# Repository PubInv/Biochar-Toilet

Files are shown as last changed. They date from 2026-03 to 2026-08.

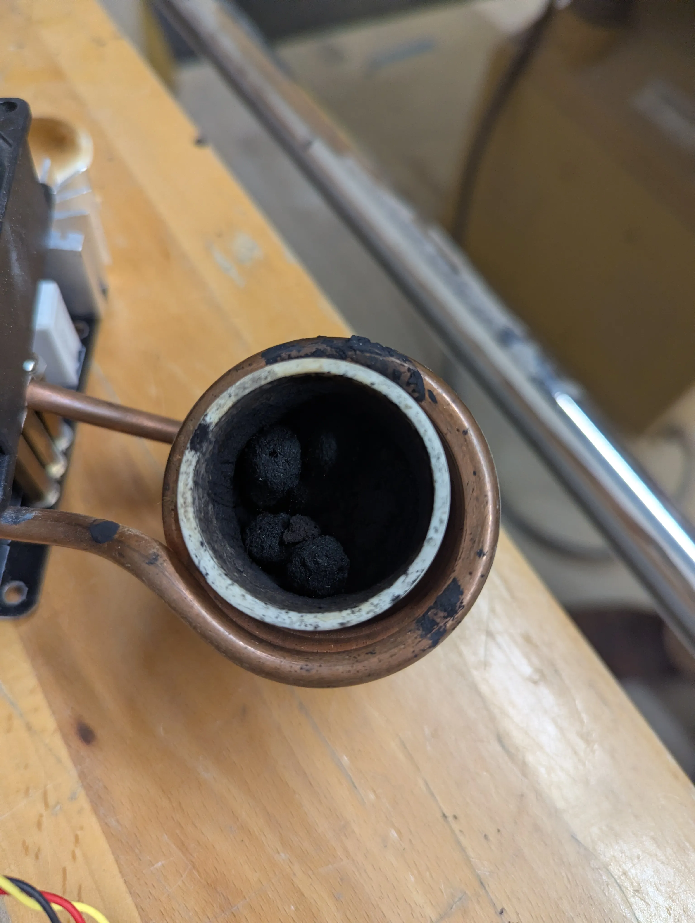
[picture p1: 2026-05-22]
images/PXL_20260327_165919695.webp

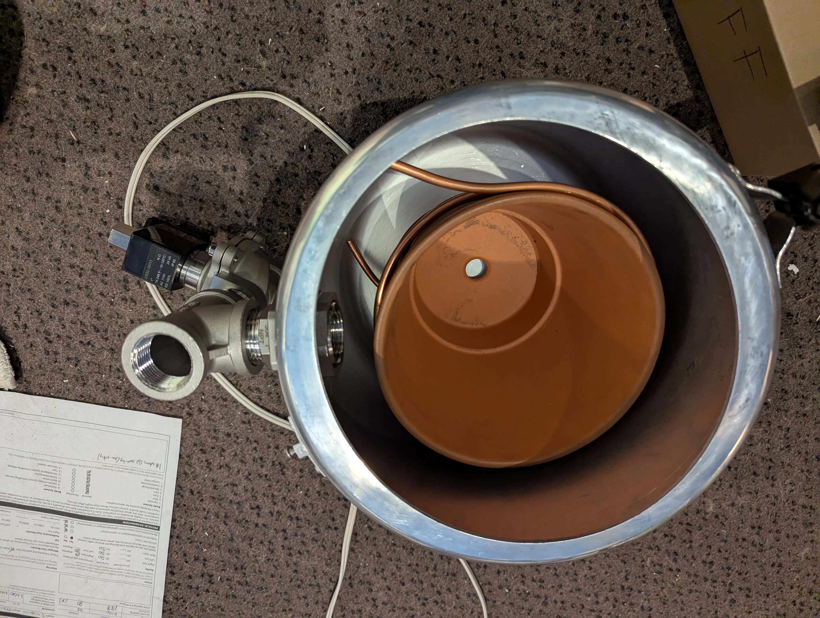
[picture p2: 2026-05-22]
images/PXL_20260417_191130522.webp

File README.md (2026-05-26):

# Current Status

Phase 1 (conductive heating prototype) is complete. All experiment data, firmware, schematics, PCB design files, and progress reports are in the [`Conductive Heating Prototype/`](https://github.com/PubInv/Biochar-Toilet/tree/main/Project%20Files/Conductive%20Heating%20Prototype) folder.

We're now in Phase 2: induction heating using a magnetite matrix. The shift from resistive heating matters because induction generates heat directly inside the charring cup — no exposed coils corroding in the process environment, and faster energy delivery to the material itself.

Ongoing experiment logs are in the [Progress Reports](https://github.com/PubInv/Biochar-Toilet/blob/main/Project%20Files/Progress%20Reports.md).

Screenshot 2025-11-21 at 6 10 39 PM

---

# Biochar Toilet

A reliable toilet that could quickly reduce human fecal matter to completely sanitary biochar would make the poorest people of the
Earth healthier. In many communities, Western-style sewage systems would be very expensive and impractical due to
geology, the lack of density in farming communities made of small land holdings, a lack of capital, and a lack of
social and political organization to dig trenches and lay pipes efficiently.

Reducing a typical human stool to biochar requires an energy input of about 600 kilojoules (see detailed analysis in referenced spreadsheet).
Even for the poorest people, the cost of this electricity is quite low---less than one US cent $0.01USD. One kilowatt hour is 3.6 MJ (megajoules).
Expensive electrical power around the world is $0.45/kWh is $0.075 USD--or less than eight cents. Even if our toilet is inefficient, it
seems possible to make a toilet whose operating cost is affordable for the poorest people, at $27.375 per year (this cost does not include
the capital costs of the toilet).

Biochar can be used as a fuel or a garden amendment. Note, however, that human stools are so small (128 grams nominally) that this is not a meaningful approach for carbon sequestration.

# Initial Design Idea

The problem of toilets is a widely researched area. Our approach may be slightly novel. We start from some assumptions:

1. Electricity is an input.
2. Complete biological safety of the end product is required.
3. We choose to temporarily ignore the capital costs of the toilet in our research.
4. Because we have to char in the absence of oxygen to prevent combustion, we can assume that we need an air-tight or pressure controlled reaction vessel.
5. A major problem in charring is to first dry the sample, and drying is primarily a problem of water transport.

We therefore conclude that our basic design will be a sealed reaction vessel with a valve that allows steam to be transported out
of the reaction chamber. We will heat the chamber contents until a desired pressure is created and then transport the water
vapor away by opening the valve. The valve will be controlled so as to avoid most gases (air) from entering the chamber.
Opening the valve will "flash" the water in the sample into steam, which will have the desirable properties of being
extremely murderous to any organisms present in the sample, and physically destructive to both plant and animal cells.
It may even physically disrupt the sample, which could be advantageous.

When the sample is sufficiently dry, we will heat it to charring temperature. When the sample is fully charred, and then cooled
and possibly wetted to avoid spontaneous combustion, the operator will be alerted that the sample is safe to remove and either combust or use as a garden amendment.

# Energy Analysis

Volunteer Nupur Bhalla working with Invention Coach Robert L. Read has produced a [Google Sheet](https://docs.google.com/spreadsheets/d/1ZwIqP0B2wM6QrpZTNiK1hNnNmIEIal7qxYdgEJz8Iog/edit?usp=sharing) representing an energy analysis of the drying and heating process.

# Heating Mechanisms

Since we will have a sealed metal reaction vessel, radio frequency (RF) heating is a possibility.
However, it is expected to become less effective as the sample dries.
We therefore intend to explore the possibility of using simple Joule resistive heating of a stainless steel vessel directly.
RF heating, however, has the advantage of heating the sample volumetrically (not requiring conduction), which may be a tremendous advantage.

# Phase 1: Conductive Heating Prototype (Complete)

Phase 1 used a pressure cooker as the reaction vessel, a hot plate controlled by an SSR, and an ESP32-based sensing system. The goal was to confirm the core architecture before committing to higher-temperature methods.

It worked. When pressure drops below ~1 PSI while temperature keeps climbing, the system correctly identifies the dry state and cuts heater power automatically. Flash decompression also checked out — opening the solenoid under pressure causes trapped water to flash to steam. A bread charring test (~110°C, 2h40m) produced a visibly charred loaf, though the dryness algorithm didn't trigger since the bread's low moisture content didn't produce a distinct enough pressure signature during drying. Soot accumulation on the lid also flagged particulate management as something to design for in future iterations.

The hard limit we hit: full charring temperatures aren't safe inside a standard pressure cooker. Lawrence Kincheloe suggested placing an inner cup (heated by a silicon nitride igniter) inside the vessel so the outer shell stays cool — that idea feeds directly into Phase 2.

We also designed a custom control PCB for this phase (ESP32-H2, v0.3.0) with dual MOSFET valve drivers, dual SSR outputs, a pressure ADC, and a MAX31855 thermocouple interface. Everything is in the [`Conductive Heating Prototype/`](https://github.com/PubInv/Biochar-Toilet/tree/main/Project%20Files/Conductive%20Heating%20Prototype) folder.

# Phase 2: Induction System Development (In Progress)

We've switched from resistive heating to pulsed induction using a magnetite matrix. The magnetite sits inside the charring cup and converts the induction field directly into heat — no exposed coils, no conduction losses through the vessel wall.

Early results from Lawrence Kincheloe and Peter are encouraging. Five grams of magnetite reached 740°F in 60 seconds; the same mass of carbon steel bearings only hit 130°F. Volume-matching the steel to the magnetite closes the gap considerably (~940°F peak), which suggests surface area and density matter more than material choice at this scale. They also charred cheese puffs at 833°F over 16 minutes in open air, with residue on the crucible cap showing evidence of partial pyrolysis.

Full experiment logs are in the [Progress Reports](https://github.com/PubInv/Biochar-Toilet/blob/main/Project%20Files/Progress%20Reports.md).

# Research Plans

The next step is pushing the induction system to actual charring temperatures — hot enough to produce biochar from organic material comparable to human stool. Work on coil geometry and magnetic field focusing is ongoing in parallel with fabrication.

Basic Biochar Toilet Design (https://github.com/user-attachments/assets/ea41856b-7663-43a1-bf12-8a3a2311aef8) 

# References

"An Experimental 13.56 MHz Radio Frequency Heating System
for Efficient Thermal Pretreatment of Wastewater Sludge",
Md. S. Ferdous, Ehssan H. Koupaie, Cigdem Eskicioglu, and Thomas Johnson*

# Volunteer Opportunities

This project is still active. If you have a background in mechanical engineering, heat engineering, or chemistry, we'd be glad to hear from you.

Reach out to Inventor Coach [Robert L. Read](https://github.com/PubInv/Biochar-Toilet/blob/main/read.robert@gmail.com) or Volunteer Coordinator [Miriam Castillo](https://www.linkedin.com/in/cstllgtrrz/). More at the [Volunteer Page](https://www.pubinv.org/volunteer/).

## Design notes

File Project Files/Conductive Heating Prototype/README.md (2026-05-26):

# Conductive Heating Prototype — Phase 1

**Biochar Toilet Project | Phase 1 Documentation** |
**Contributor:** Hardhik Pyla ([@hardhik03](https://github.com/hardhik03)) |
**Period:** November 2025 – May 2026 |
**Status:** Complete

---

## Overview

Phase 1 of the Biochar Toilet project was a proof-of-concept prototype to validate the core system architecture before advancing to higher-temperature charring methods. The goal was to build the smallest, safest system possible — one that could demonstrate:

1. Reliable pressure and temperature sensing inside a sealed reaction vessel
2. Automatic dryness detection using temperature–pressure divergence logic
3. Autonomous heater shutoff via SSR when the dry state is detected
4. Flash decompression: opening a solenoid valve under pressure to flash-boil trapped water into steam (providing mechanical sterility)

The reaction vessel was a standard pressure cooker. The heating source was a hot plate controlled by a solid-state relay (SSR). Sensing and control were handled by an ESP32-based embedded system, later migrated to a custom-designed control PCB.

---

## System Architecture

```
[Pressure Cooker] ──── [K-type Thermocouple] ───► [ESP32-H2 Control Board]
      │                                                      │
      ├──── [Analog Pressure Sensor] ───────────────────────►│
      │                                                      │
      └──── [Solenoid Valve 1] ◄──── [MOSFET Driver] ◄──────┤
                                                             │
[Hot Plate] ◄──── [SSR 1] ◄──── [NPN BJT Driver] ◄──────────┘
```

**Dryness Detection Logic:**
When pressure drops below ~1 PSI and stays there for 15 seconds (after an initial active cycle above 2 PSI), the system latches the "dry" flag and disables the heater SSR. This is based on the observed behavior that temperature rises sharply while pressure stays low once all moisture has been driven off.

**Valve Control Logic:**
The solenoid valve opens when pressure reaches 8 PSI and closes at 7 PSI (hysteresis band), releasing steam to the condenser/containment vessel.

**Temperature Control:**
A proportional controller (Kp = 0.03) targets 200°C with a 2-second PWM window. An exponential moving average (α = 0.10) smooths thermocouple readings.

---

## Hardware

| Component | Description |
|---|---|
| Reaction vessel | Standard pressure cooker |
| Microcontroller | ESP32 (breadboard) → ESP32-H2 DEVKITM-1-N4 (custom PCB) |
| Temperature sensor | K-type thermocouple + MAX31855 breakout (SPI) |
| Pressure sensor | Analog 0–100 PSI, read via ADC with voltage divider (0–5V → 0–3.3V) |
| Solenoid valve | 12V solenoid, driven by IRLB3813PBF N-channel MOSFET |
| Heater control | Solid-state relay (SSR 1), NPN BJT driver — active HIGH |
| Hot plate | External AC hot plate, switched via SSR |
| Custom PCB | Bio-Char Control Board v0.1.0 (KiCad 9, 2-layer FR4, ~$48 BOM) |

---

## Pin Configuration

The table below reflects the **working firmware pin assignments** as validated during PCB bring-up. These differ from the original KiCad schematic assignments — see the [Pin Change Notes](#pin-change-notes) section below.

| GPIO | Function | Direction | Notes |
|---|---|---|---|
| GPIO0 | MAX31855 CLK | Output | SPI clock |
| GPIO1 | MAX31855 CS | Output | SPI chip select |
| GPIO2 | MAX31855 DO | Input | SPI MISO — read-only, no MOSI needed |
| GPIO3 | Pressure Sensor ADC | Input | ADC1_CH3, 0–100 PSI via voltage divider |
| GPIO4 | SSR 1 / Heater | Output | **Active HIGH** — drives NPN BJT base to complete SSR circuit |
| GPIO5 | SSR 2 | Output | Reserved — not currently active (see firmware comments) |
| GPIO10 | Solenoid Valve 1 | Output | MOSFET (IRLB3813PBF) driven |
| GPIO11 | Solenoid Valve 2 | Output | Reserved — not currently active (see firmware comments) |

### Pin Change Notes

During PCB bring-up, the SSR control pins had to be remapped due to a conflict with the ESP32-H2's internal crystal peripheral:

- **GPIO13 and GPIO14** are internally tied to the ESP32-H2's 32 kHz RTC crystal oscillator. The original schematic routed SSR1 and SSR2 control lines to these pins. On Test 1 (05/06/2026), both SSR outputs were unresponsive — the GPIOs could not be driven as outputs while the crystal is active.
- As a Test 1 workaround, SSR1 and SSR2 were manually driven from **GPIO4 and GPIO5** (open pins on the board), confirming the BJT and SSR circuitry was otherwise functional.
- On 05/14/2026, the GPIO13 and GPIO14 traces were physically cut and jumper wires were soldered from GPIO4 → SSR1 and GPIO5 → SSR2 pads. This hardware rework makes the board match the firmware pin assignments permanently.
- The corrected routing will be incorporated into the next PCB design revision.

### Heater/SSR Logic Change

The original Arduino firmware used **active LOW** logic for the heater (GPIO4 LOW = SSR ON, sinking to GND via the SSR's internal optocoupler). The PCB design introduced an NPN BJT between the ESP32 GPIO and the SSR input, which inverts the signal:

```
GPIO4 HIGH → BJT base HIGH → collector pulls SSR input → SSR ON
GPIO4 LOW  → BJT OFF       → SSR input floating        → SSR OFF
```

The ESP-IDF firmware (`Firmware/main/main.c`) uses **active HIGH** accordingly. The `set_heater()` function drives GPIO4 HIGH to turn the heater on and LOW to turn it off.

---

## Known Errors and Issues

| # | Issue | Status | Notes |
|---|---|---|---|
| 1 | ADC non-linearity at low raw values (<350) | Mitigated | Readings below ~0.5 PSI fluctuate. DRY_PRESSURE_MAX threshold (1.0 PSI) provides sufficient headroom for reliable detection. |
| 2 | MAX31855 returns NaN on first read after power-on | Handled | ~100ms settling time required. EMA initialisation stays NaN until a valid reading arrives — no false triggers. |
| 3 | GPIO3 shared with JTAG MTDI | Known | Disconnect JTAG debugger before running in production, or remap ADC to GPIO4/5 if debugging under sustained load. |
| 4 | GPIO13/GPIO14 RTC crystal conflict — SSR pins non-functional | Resolved (05/14/2026) | Original schematic routed SSR1/SSR2 to GPIO13/GPIO14, which are internally tied to the 32 kHz RTC crystal on the ESP32-H2. Confirmed on Test 1 (05/06): both SSR outputs were unresponsive. Test 1 workaround: SSR driven manually from GPIO4/GPIO5. Permanent fix: traces to GPIO13/GPIO14 cut and jumper wires soldered to GPIO4/GPIO5 pads. Next PCB revision will correct the routing. |
| 5 | D2/D5 diode voltage drop — solenoid safety switches not opening | Resolved (05/14/2026) | 1N4148 diodes on the solenoid valve safety switch circuits had a forward voltage drop high enough to prevent the gate logic from pulling low cleanly, blocking valve operation. Bypassing the diodes confirmed the MOSFET/solenoid path was functional. D2 and D5 replaced with 1N4001 diodes; valve operation re-verified successfully. |
| 6 | Bread charring — dryness detection did not trigger | Investigated | Bread had insufficient initial moisture to produce a distinct pressure signature during drying. Detection heuristic works correctly for water-heavy samples. |

---

## Experiment Timeline

See [`Progress Reports.md`](https://github.com/PubInv/Biochar-Toilet/blob/main/Project%20Files/Progress%20Reports.md) for full dated entries. Summary:

| Date | Milestone |
|---|---|
| Nov 21, 2025 | Pressure sensor schematic designed |
| Dec 5, 2025 | Initial pressure sensor physical calibration and error testing |
| Dec 11, 2025 | Dryness detection breadboard prototype — valve, pressure, dryness logic validated |
| Jan 16, 2026 | Microcontroller + solenoid valve + SSR hardware integration |
| Feb 13, 2026 | Bread charring test with auto-shutoff — end-to-end system validated |
| Mar 5–18, 2026 | Custom Control Board PCB design (v0.1.0) — Gerbers generated |
| May 6, 2026 | PCB Board Test 1 — PSI and dry detection verified; GPIO13/14 crystal conflict and D2/D5 diode drop identified |
| May 14, 2026 | Hardware rework — GPIO13/14 traces cut, SSR lines jumpered to GPIO4/5; D2/D5 replaced with 1N4001; valve operation re-verified |

---

## Key Results

**Dryness Detection:** Successfully confirmed. When pressure falls below 1 PSI for 15 sustained seconds following an active cycle, the system correctly identifies the dry state and disables the heater.

**Flash Decompression:** Validated. Opening the solenoid valve under pressure causes water to flash to steam. However, at ~15 PSI, the valve restriction prevented instantaneous pressure drop — steam flowed continuously rather than flashing off in a single burst.

**Bread Charring Test (Feb 13, 2026):** A loaf of bread was heated inside the sealed pressure cooker at ~110°C for approximately 2 hours and 40 minutes. The loaf was visibly charred. The dryness detection algorithm did not trigger in this run (see Known Errors #5). Soot accumulation on the chamber lid was observed, raising particulate management as a future design concern.

**Key Finding — Safety Limit:** Full charring temperatures cannot be safely reached inside the pressure cooker vessel. Lawrence Kincheloe proposed an inner charring cup (heated by a silicon nitride igniter) inside the pressure cooker, keeping the outer vessel cool. This informed the transition to Phase 2 (induction heating).

---

## Firmware

Two firmware versions exist for this prototype:

| File | Platform | Notes |
|---|---|---|
| `Firmware/main/main.c` | ESP-IDF v5.x | Current — active HIGH heater logic, reserved pins commented |
| *(Arduino reference)* | Arduino IDE | Original breadboard firmware; superseded by ESP-IDF version |

The ESP-IDF firmware (`Firmware/main/main.c`) implements all three control loops simultaneously:
- Pressure-based valve hysteresis (8 PSI on, 7 PSI off)
- Dry boiler detection (sustained low-pressure latch after active cycle)
- Proportional temperature control with EMA smoothing and 2-second PWM window

To build and flash:
```bash
idf.py set-target esp32h2
idf.py build
idf.py -p PORT flash monitor
```

Root-level Python scripts (`dryness_monitor.py`, `valve_controller.py`, and their tests) were earlier-stage software prototypes for the same logic.

---

## PCB Design

The Bio-Char Control Board v0.1.0 is documented in detail in the main project PCB Design folder. Key specs:

- **MCU:** ESP32-H2-DEVKITM-1-N4 (RISC-V 96MHz, WiFi 802.11n, BLE 5.2)
- **Power:** 12V input → R-78E5.0-1.0 switching regulator (5V) + 2A PTC fuse + reverse-polarity protection
- **Outputs:** 2× IRLB3813PBF MOSFET solenoid drivers, 2× NPN BJT-driven SSR outputs (active HIGH)
- **Sensors:** MAX31855 SPI thermocouple, analog pressure ADC with voltage divider
- **BOM cost:** ~$48 (Mouser, March 2026)
- **Manufacturing files:** Gerbers and drill files included

---

## Conclusions and Lessons Learned

1. Temperature–pressure divergence is a reliable proxy for sample dryness and works well as an autonomous shutoff trigger.
2. Valve restriction geometry matters significantly for flash decompression — a lower-restriction valve is needed for true instantaneous pressure drop.
3. Low-moisture samples (like dry bread) do not produce a clear pressure signature during drying, requiring either a different detection heuristic or moisture pre-conditioning.
4. Soot and particulate management inside the reaction vessel needs to be designed for from the start in future iterations.
5. Charring temperatures (>400°C) cannot be safely achieved in the pressure cooker configuration — an inner heated vessel is necessary.
6. The custom PCB successfully consolidates all sensing and control onto a single board, validating the embedded architecture for future phases.
7. Crystal-reserved GPIOs on the ESP32-H2 (GPIO13, GPIO14 for the 32 kHz RTC crystal) must be identified and avoided during schematic design — they appear usable in simulation but are unresponsive as outputs on hardware while the crystal is active.
8. 1N4148 diodes are inadequate for solenoid valve safety switch circuits at the currents involved — the forward voltage drop prevents clean gate logic switching. 1N4001 is the correct replacement.

---

## Files in This Folder

```
Conductive Heating Prototype/
├── README.md                        ← This file
└── Firmware/
    ├── CMakeLists.txt               ← ESP-IDF top-level build file
    └── main/
        ├── CMakeLists.txt           ← Component registration
        └── main.c                   ← ESP-IDF integrated control firmware
```

Hardware files (schematics, PCB design, test videos) are in the corresponding subfolders of the main project directory and cross-referenced above.

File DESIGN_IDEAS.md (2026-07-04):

This design solves two big problems: **thread fouling** (bentonite dust destroys threads) and **mechanical complexity** (clamps/bolts require extra parts).

Here is how to adapt this cookware concept into a rugged industrial sanitation device.

### 1. Why this works for "Severe Service" (Dust + Pressure)

The oval lid is that the **lid itself is physically larger than the hole** along one axis.

* **Blowout Proof:** In a standard "outside" lid, if the bolts fail, the lid becomes a projectile. In this "inside" design, the pressure pushes the lid *against* the metal rim of the chamber. It is mechanically impossible for the lid to blow off while pressurized.
* **Foul-Resistant:** Because there are no threads, there are no small crevices for your bentonite/magnetite dust to pack into. If dust gets on the rim, the massive force of the internal pressure (the "self-energizing" effect) will simply crush the gasket over the dust, maintaining the seal.

### 2. The Geometry: How to Manufacture It

You do not need complex castings. You can manufacture this using standard stainless steel plate.

* **The Shape:** Both the chamber opening and the lid are **Ellipses** (ovals).
* *Example:* If your opening is 6 inches wide (minor axis) and 7 inches long (major axis), your lid would be 6.5 inches wide and 7.5 inches long.

* **The Insertion Motion:** To insert the lid, you turn it 90 degrees so the lid's *short* side fits through the hole's *long* side. Once inside, you rotate it back 90 degrees and pull it up.
* **Material:** 316 Stainless Steel is ideal for urine/corrosion resistance.

### 3. Adapting for Automation (The "Internal Hinge")

The only downside of the Indian cooker design is that it requires a complex human hand motion (insert, twist, rotate, pull). To make this "mechanically simple" for a device that might be automated or operated easily by a user:

**Add a Single Internal Hinge.**
Instead of a loose lid, attach the oval lid to a hinge *inside* the vessel.

* **Operation:** When the user (or actuator) pushes a lever, the lid swings down and "collapses" slightly into the chamber.
* **Closing:** A spring pulls the lid back up against the hole.
* **Benefit:** This keeps the lid aligned perfectly every time. The user doesn't have to fiddle with the geometric puzzle of fitting the oval through the hole; the hinge guides it.

### 4. The Seal Interface (Combining your ideas)

To make this work with the "high compliance" idea:

1. **The Gasket:** Place a thick, soft **Silicone or EPDM gasket** around the *top rim* of the oval lid.
2. **The Seat:** The rim of the chamber opening should be smooth.
3. **The "Pre-Tension":** You mentioned a "partial seal." In the Indian cooker, a handle clips onto a bar to pull the lid up gently. For your device, use a **Simple Cam Lever**.
* *Step 1:* User drops lid in.
* *Step 2:* User pulls a small lever that pulls the lid up with ~5 lbs of force. This squishes the soft gasket just enough to make it airtight.
* *Step 3:* Induction starts -> Pressure builds -> Lid seals with 1000+ lbs of force.

### 5. Specific Caution: Induction Heating

* **Risk:** If your induction coils are wrapped around the *outside* of the stainless steel chamber near the lid, the **lid itself might heat up** via induction, potentially melting your gasket.
* **Solution:** Ensure your induction coils are focused lower down on the magnetite payload, or use a non-conductive ceramic/composite spacer ring between the heated zone and the steel sealing rim.

### Summary

It is the most robust, fail-safe, and foul-resistant pressure vessel design available.

* **Action:** Design an elliptical opening.
* **Seal:** Top-mounted gasket on the lid.
* **Mechanism:** "Drop, Twist, Pull" (manual) or "Internal Hinge" (semi-auto).

---

## Update: Critical Design Decision - The "Potted" Internal Coil

This is a critical design decision.

For your specific goal—heating the **Magnetite** directly (to use its high surface area for rapid evaporation)—the answer is **INSIDE**.

### The Physics: Why "Outside" Fails

If you wrap induction coils around the *outside* of a stainless steel or aluminum pressure vessel:

1. **Faraday Cage Effect:** The metal wall will intercept the magnetic field.
2. **Wall Heating:** The induction energy will heat the **chamber wall**, not the magnetite. The wall will get extremely hot, and the magnetite will only heat up slowly via conduction from the wall. This defeats the purpose of using magnetite as a volumetric heating element.
3. **Aluminum Efficiency:** If you use Aluminum, it is so conductive that it will reflect/absorb almost 100% of the field instantly.

### The Solution: The "Potted" Internal Coil

You must place the coils **inside** the pressure boundary, but you cannot expose bare copper coils to urine and abrasive clay.

* **Design:** Cast the copper induction coil inside a cylinder of **high-temperature refractory cement** or **castable silicone**.
* **Function:** This creates a "removable liner" (like a bucket). The waste goes inside this liner.
* **Safety:** The Stainless Steel pot handles the **pressure**. The Ceramic Liner handles the **electricity and heat**.

### 2. The Magnetite Catalyst (CO & NOx Killer)

Magnetite acts as a dual-function catalyst here:

1. **Oxidation:** Converts Carbon Monoxide () to Carbon Dioxide ().
2. **De-NOx (SCR):** Your waste contains **Urine** (Ammonia/Urea). In the presence of Magnetite and heat, the Ammonia reacts with Nitrogen Oxides () to form harmless Nitrogen () and Water. This is the exact principle used in diesel trucks (SCR), but you are generating your own "Diesel Exhaust Fluid" (ammonia) from the urine!

**Heating Method:**

* **Do not use a second induction coil.** It adds massive complexity (interference between coils, dual power supplies).
* **Use a Cartridge Heater.** A simple, robust stainless steel heating rod inserted down the center of your catalyst tube. It is cheap, easy to control (PID), and robust.

### 3. Updated Design: The "All-in-One" Lid Assembly

* **The Pot:** Remains a simple Oval shell.
* **The Liner:** Remains the Ceramic/Induction bucket.
* **The Lid:** Now features a **"Reaction Tower"**.
* **Bottom:** Steam Valve.
* **Middle:** Magnetite Catalyst Chamber (heated).
* **Top:** Clean Exhaust Outlet.

### 4. Technical Explanation of the "Tower"

#### A. The Steam Cleaning Valve (Blue Block)

* **Placement:** Directly above the lid center hole.
* **Logic:** The valve is the "Gatekeeper."
* **Phase 1 (Cooking):** Valve Closed. Pressure builds to 15 PSI. Temperature hits 121°C. Sterilization occurs.
* **Phase 2 (Venting):** Valve Opens. The 15 PSI pressure blasts steam through the valve. This high velocity prevents "gunk" from settling on the seat.
* **Component:** Use a **PTFE-seated Stainless Steel Solenoid Valve** (rated for >180°C steam).

#### B. The Magnetite Catalyst (Dark Grey Cylinder)

* **Placement:** Immediately *after* the valve.
* **Why here?** The gas leaving the valve is hot, but maybe not hot enough for catalysis (needs ~300°C+).
* **The Heater (Gold Rod):** A **Cartridge Heater** runs down the center of the pipe.
* It heats the Magnetite pellets surrounding it to ~350°C.
* As the VOCs, CO, and Steam pass through the hot pellets, they are "cracked" and oxidized.
* **Efficiency:** Because the gas is forced through the hot pellet bed, contact time is high. The "Cartridge Heater in the Center" is the most energy-efficient way to heat a gas stream (heating from the inside out).

#### C. Electrical Feedthrough (Goldenrod)

* Since the coil is inside the pot, we need to get power to it.
* The Lid has a **High-Amperage Ceramic Feedthrough**.
* **Connection:** When you lower the lid into the pot, you plug the coil into the bottom of the lid (using a high-temp connector like a ceramic terminal block), then twist and lock the lid.

### 5. High-Temperature Bottom Cartridge (H2S Scrubbing)

To prevent downstream corrosion of the steam valve and heat exchanger, a high-temperature scrubbing cartridge is integrated at the bottom of the vessel.

* **Placement:** Located at the base of the reaction vessel, serving as the exit "choke point" for the downdraft gas flow.
* **Composition:** A modular Silicon Carbide (SiC) and Magnetite matrix.
* **Function:** Operates at peak induction temperatures (800°C+) to chemically strip Hydrogen Sulfide (H₂S) from the syngas stream before it exits the vessel. This protects the stainless steel solenoid valve and thermal recovery hardware from sulfuric acid corrosion.
* **Maintenance:** Designed as a drop-in replaceable cartridge.

---

## Future Phases: Syngas Processing and Advanced Catalysis

For detailed engineering considerations on managing exhaust gases, practical lean combustion syngas conversion, and sulfur mitigation strategies within the biochar mix, please refer to the advanced Phase 3 memo: [Syngas Processing Memo](Project Files/Memos/Syngas_Processing_Memo.md).

---

## System Monitoring & Valorization

The project utilizes a pressure cooker, modified with a 1" solenoid and an integrated induction heating loop. The induction loop itself is quite large, needing to encompass human fecal matter. The system uses a pressure sensor to monitor the state of the system; because we use pressure, we can monitor the state of valorization.

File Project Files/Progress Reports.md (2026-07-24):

## **[07/24/2026]**

**Phase 3 Ideation – Physical System Frame Design**

Worked in FreeCAD 1.1 to pull together Hawkins 12L Pressure Pot assembly components and to start initial system frame rigging design using 20mm x 40mm extruded aluminum and compatible hardware. Uploaded current FCStd file status into the Public Invention/Biochar-Toilet/Project Files/CAD Files folder as "Frame for Assembly_v2.FCStd". Once all essential components are uploaded, and component assembly layout has been established, specific joint bracket hardware will be added to a parts list to create a Frame BOM, and custom brackets will be designed and sent to fabrication as-needed, with details uploaded to Frame BOM. 

## **[07/03/2026]**

**Phase 3 Ideation – High-Temperature H2S Scrubbing Refinement**

Refined the Phase 3 sulfur mitigation strategy by proposing a high-temperature Silicon Carbide (SiC) and Magnetite cartridge at the bottom of the reaction vessel. This cartridge serves as the final high-temperature "choke point" (800°C+) for downdraft syngas, maximizing H2S removal efficiency before the gas reaches the solenoid valve and external heat recovery hardware. This addition completes the three-tier sulfur defense architecture: in-situ fixation (biochar), peak-temp scrubbing (bottom cartridge), and low-temp polishing (iron sponge). Updates were applied to the [Syngas Processing Memo](Memos/Syngas_Processing_Memo.md) and `DESIGN_IDEAS.md`.

## **[07/01/2026]**

**Phase 3 Ideation – Syngas Processing and Ceramic Liners**

Documented advanced Phase 3 concepts regarding the management of syngas exhaust and modular ceramic liner assemblies. A new engineering memo was created detailing the highly practical lean combustion pathway for oxidizing Syngas into CO₂, and exploring sulfur mitigation strategies directly within the biochar mixture using in-situ fixation and Iron Sponge dry scrubbers. Furthermore, design guidelines for "leaky" modular ceramic assemblies with slip-fit baffles were established to prevent thermal shear failure in the heat exchanger. The complete analysis is recorded in the [Syngas Processing Memo](Memos/Syngas_Processing_Memo.md) and linked in `DESIGN_IDEAS.md`.

## **[06/17/2026]**

**Post presentation notes on live demo**

Firmware needed a slight update to assign  
main.c file: #define PIN_ADC_PRESSURE ADC_CHANNEL_3 // GPIO3, should be  ADC_CHANNEL_2

The DC SSR and battery combo was controlled with a simple momentary switch, which worked well for testing the induction heater. It was found that the coils were shorting out, which created a large spark and irratic performance of the heater. It is assumed that the spark created an inductive spike which may have blown a hole in the capacitors, which may be self healing. Normal operation resumed after some time, however this may be due to other factors. 

The water became steaming hot, and we need to integrate in a radiator into the system. 

High water content fruit, such as raspberries, do not produce much char and additonally do not make as much noxious odors. 

The hot plate bio char pot developed a stuck seal, such that it wouldn't pressurize. It's assumed that the gasket became fouled or not enough moisture is present to engage the pop up locking valve pin. This failue mechanism is not on the oval pot, which uses positive pressure on the entire lid to prevent inadvertant lid removal. 

We were able to biochar or induce pyrolysis with the hot plate version, it took about 2 hours to stop seeing significant steam/smoke/vapor from the leaking seal. 

We demonstrated that magnetic seperation worked with the magnetite mixed sample, using a harddrive magnet and a glass test tube. An electromagnet or a rotating magnet bar would be ideal for this application in the future. 

We should have created a fresh batch of tested mix, our existing mix may not be performing optimally. We also need to run more tests with water and fully drying times.

## **[05/14/2026]**

**PCB Control Board – Trace Rework and Hardware Fixes**

Following Test 1 findings, Hardhik performed hardware rework on the Bio-Char Control Board (v0.1.0) to resolve the two issues identified on 05/06:

GPIO13 and GPIO14 traces to the SSR control lines were physically cut on the PCB. Jumper wires were soldered from GPIO4 and GPIO5 directly to the SSR1 and SSR2 pads respectively, bypassing the original routing. This brings the hardware into alignment with the current firmware pin assignments. The trace cut and remap will be incorporated into the next PCB design revision.

Diodes D2 and D5 (1N4148) on the solenoid valve safety switch circuits were desoldered and replaced with 1N4001 diodes. The 1N4148's forward voltage drop under the switch current was high enough to prevent the safety switches from pulling the gate logic low cleanly, keeping the solenoid valves from opening. The 1N4001's lower drop at higher currents resolved this. Valve operation was re-verified after the swap and both solenoids opened and closed correctly.

These changes are hardware-only, no firmware modifications were required.

**PCB Control Board – Initial Testing (Test 1)**

Hardhik conducted the first round of physical tests on the assembled Bio-Char Control Board (v0.1.0). The test session covered four areas of the board's integrated control firmware, but also uncovered two hardware issues that required rework.

PSI readings from the analog pressure sensor were confirmed correct across the expected range. ADC-to-PSI calibration constants (ADC_ZERO = 320, ADC_FULL = 3008) were validated against a reference gauge. The dry-boiler detection logic also worked as expected — after a sustained pressure drop below 1 PSI for 15 seconds following an active cycle, the dryLatched flag triggered and the heater SSR was disabled correctly. A full-system Serial readout at 115200 baud was recorded showing pressure, valve, heater, and temperature simultaneously.

Two hardware faults were found:

**SSR pins non-functional (GPIO13/GPIO14 crystal conflict):** GPIO13 and GPIO14 on the ESP32-H2 are internally tied to the 32 kHz RTC crystal oscillator and cannot be used as general-purpose outputs. The original schematic routed the SSR1 and SSR2 control lines to these pins. As a workaround for Test 1, the SSR lines were driven from GPIO4 and GPIO5 (open pins), confirming the SSR and BJT circuitry itself works correctly once a valid GPIO is used. A permanent trace rework was scheduled.

**Solenoid valve safety switches not opening (D2, D5 diode voltage drop):** Diodes D2 and D5 (1N4148) on the solenoid valve safety switch circuits had a higher-than-expected forward voltage drop under the switch current, which prevented the gate logic from pulling low cleanly and kept the valves from opening. The valves were tested by bypassing the diodes to confirm the MOSFET and solenoid circuits were otherwise functional. Replacement with 1N4001 diodes was scheduled.

Valve hysteresis (8 PSI open, 7 PSI close) was verified using the GPIO4/GPIO5 workaround after identifying the GPIO13/GPIO14 issue.

## **[04/24/2026]**
Lawrence and Peter ran a series of experiments with different amounts of material that we want to use for induction heating. 
The temperature measurements are located in [Induction experimental data.md](https://github.com/PubInv/Biochar-Toilet/blob/main/Induction experimental data.md)
Interestng results were that we didn't hit the curie temperature of the carbon steel, as evident by the thermal readings and the presence of a magnetic field. Based on
color charts for steel and our measurements, we estimate we got up between 900-1000 degrees F for the pure ball bearing. 

Quick Observations
The Magnetite Advantage: At 5 grams, the Magnetite is significantly more efficient at converting the induction field to heat compared to the same mass of Carbon Steel bearings (reaching 740°F vs 130°F in 60 seconds).

Volume vs. Mass: The Carbon Steel only starts to compete in peak temperature (940°F) when the volume is matched to the Magnetite, suggesting density and surface area are playing a massive role here. 
It is believed that this is due to eddie currents, which seem to favor lengh wise induced current when the material is making good electrical contact. 

The "Mixed" Thermal Inertia: The mixture shows a much more gradual and staggered climb, likely due to the Bentonite acting as a thermal buffer or insulator between the active heating elements.
Further adjustments to the mix will need to be determined to balance thermal heat transfer, rapid heating, and options for agitation. 

Peter will drill out the holes for the induction heater next week, and we are continuing to debug issues with the higher power induction coil. 
Right now we suspect the issue may be the spacing on the coils (currently 10-30mm), but it's interesting to note that coil geometry has a large effect on heating potential. 
We may need to accelerate our understanding of coil geometry and options for focusing the magnetic field towards the center of the crucible.

## **[03/27/2026]**
Lawrence and Peter ran an experiment attempting to char cheese puffs. The cheese puffs are about 8mm in diameter, 
and there were about 6 of them in the crucible, moistened with water and coated in mostly magnetite with some kitty litter.
The induction coil system had been running for about 5 minutes when the mixture began smoking. The max temperature attained was 833F before the team put a cap on the 
system at the 9 minute marker (an arbitrary amount of time).

Once the system had cooled to safe handling temperature, the team opened the lid to discover the results were good. All but one of the cheese puffs all charred all 
the way through. This experiment was conducted in the open air (oxygen-rich) so pyrolysis was not as efficient, but there WAS evidence of some pyrolysis happeneing, 
due to the residue on the crucible cap.

The total powered time of this experiment was about 16 minutes. 

## **[03/20/2026]**
Lawrence and Peter had identified and (Lawrence) updated the project BOM with the bulkhead fittings and hardware required for the induction coil 
system to insulate the energized copper from the aluminum pot, as well as to seal the fitting and lock the insulated sleeve in place using a 
furrel nut and insolating washer. They also identified 440 stainless steel shot 2mm as being an excellent starting point for mixing with
the magnetite.

Peter had digitized the bounding box of the induction module (for clearance) and the model of the 1" air line's bulkhead fitting;
he also imported STEP files of the PSU and T-Pipe fitting. The purpose for this is to create proper mounting systems contining the 
components to make a solid, safe, transportable unit for demonstration and experimentation.

## **[03/18/2026]**

**Bio-Char Control Board PCB – v0.1.0 Design Complete**

Hardhik completed the design and manufacturing file generation for the Bio-Char Control Board v0.1.0, an ESP32-H2-based industrial control PCB purpose-built for the bio-char production system. The design work ran from March 5 through March 18, spanning 14 KiCad revision checkpoints.

The board integrates the full sensor and control stack onto a single 2-layer FR4 PCB:
- **Microcontroller:** ESP32-H2-DEVKITM-1-N4 (RISC-V 96MHz, WiFi 802.11n, BLE 5.2, Thread/Zigbee capable)
- **Power management:** 12V input → R-78E5.0-1.0 switching regulator (5V, 95% efficiency) with 2A PTC resettable fuse and reverse-polarity protection diode
- **High-power outputs:** 2× IRLB3813PBF N-channel MOSFETs for solenoid valve control (upgraded from IRLB8721PBF for lower Rds(on) of 2.3mΩ and higher current headroom); 2× NPN transistor-driven SSR outputs
- **Sensors:** MAX31855 K-type thermocouple breakout (SPI, −200°C to +700°C) and analog pressure sensor input with voltage divider (0–5V → 0–3.3V)
- **Safety:** Flyback diodes on all inductive loads, manual override switches for both solenoids, Phoenix Contact screw terminals throughout

The complete BOM was finalized and verified against Mouser Electronics pricing: 40 components across 18 types at a total cost of ~$48 (as of March 2026). Gerber files and NC drill files were generated and are ready for fabrication at JLCPCB, PCBWay, or OSH Park using standard 2-layer, 1.6mm FR4, 1oz copper settings.

## **[03/06/2026]**
Lawrence and Peter were able to fill a crucible with 100% magnetite and a cup of water, then using only the induction coil 
system, was able to evaporate all of the water in less than 8 minutes, starting with the sample at room temperature.
Next steps towards biochar include testing different ratios of kitty litter (bentonite), magnetite, and mild steel shot to not only
evaporate water quickly, but to char an organic sample. 
Data will be collected then analyzed via spreadsheet graph comparison.

## **[02/13/2026]**

**Dryness Detection + Auto Shutoff – Bread Charring Test**

Hardhik ran a combined dryness-detection and automatic shutoff test using bread as the organic sample. The system consisted of the microcontroller connected to a solenoid valve and an SSR-controlled hot plate. Key hardware integrations documented in this session included the SSR wired to the hot plate and the microcontroller-to-valve connection.

The bread was placed in the charring vessel and the system was powered on. The hot plate heated the sample while the pressure sensor monitored internal pressure. The dryness detection logic — which tracks a sustained low-pressure window after an initial active cycle — successfully identified when the material had dried sufficiently and triggered the auto shutoff, cutting power to the hot plate via the SSR.

The charred bread result showed visible and complete charring throughout the sample. This confirmed that the integrated dryness detection and automatic shutoff pipeline works end-to-end: the system can autonomously stop heating once the organic material is processed, without requiring manual intervention.

Video evidence of the test process and the final charred bread result were captured for documentation.

## **[01/16/2026]**

**Dryness Detection + Valve Auto Shutoff – Hardware Integration**

Hardhik integrated the microcontroller, solenoid valve, and SSR into a working prototype for the dryness detection and auto-shutoff system. Prior breadboard work was assembled into a more connected configuration, with the valve and SSR now driven directly by the ESP32 GPIO outputs.

Multiple video recordings were captured documenting the valve actuation behavior, the sensor feedback loop, and overall system operation. The system demonstrated the ability to open and close the solenoid valve based on pressure thresholds, while independently managing the heater SSR through the temperature control loop — operating both control loops concurrently without interference.

This session established the core firmware architecture (pressure-based valve hysteresis + dry detection + proportional temperature control) that later became the basis for the PCB firmware.

## **[12/11/2025]**
**Dryness Detection – Breadboard Prototype**

Hardhik built and tested an initial breadboard prototype for dryness detection. The circuit connected a pressure sensor and solenoid valve to an ESP32 microcontroller to test the concept of detecting when a heating cycle has driven off all moisture from a sample.

Key tests conducted in this session:

- **Dryness Detection:** The system successfully distinguished between an "active" pressurized state and a "dry" low-pressure state, validating the logic of using pressure as a proxy for remaining moisture in the system.
- **Pressure Sensor Check:** The sensor readings were verified on the breadboard against known pressure values.
- **Valve Turning ON / OFF:** The solenoid valve was confirmed to open and close correctly under GPIO control at the expected pressure thresholds.

The breadboard circuit provided confidence in the sensing and actuation approach before moving toward a more permanent hardware integration.

## **[12/05/2025]**
**Pressure Sensor – Initial Physical Testing**

Following the pressure sensor schematic work (Nov 21), Hardhik conducted the first physical pressure sensor tests. Two recordings were captured: one showing successful pressure sensor calibration against a reference, and one documenting a sensor error condition (likely an out-of-range or wiring issue) to characterize failure modes.

The calibration session established the ADC-to-PSI mapping that would later be formalized in firmware (ADC_ZERO ≈ 320, ADC_FULL ≈ 3008 for 0–100 PSI full-scale). Understanding the error behavior of the sensor was an important step for designing reliable dryness detection logic in subsequent firmware iterations.

## **[11/21/2025]**
**Pressure Sensor – Schematic Design**

Hardhik designed the initial pressure sensor schematic for the Phase 1 prototype. The schematic documents the sensor wiring, voltage divider configuration (0–5V → 0–3.3V for ESP32 ADC compatibility), and connector pinout. This served as the hardware reference for subsequent physical testing and was later incorporated directly into the Control Board PCB design.

## **[11/07/2025]**
**Flash System Prototype - Test 1**

On Nov.7th an initial prototype was tested. This consisted of a pressure cooker containing a cup of water,
with a thermocouple added and a hose connected to an electronic valve, leading to a condenser.

This experiment was largely confirmatory of our approach, but we learned certain things:
1. At high power and about 15 psi, the steam does not "flash" off. When the valve is opened, the
steam escapes, but it keeps flowing. Our valve apparently produces so much restriction that the
pressure does not drop quickly (though it does drop, but remains positive).
2. The temperature did rise DRASTICALLY when the water dried up. Our theory that we can detect this by the time that the pressure ceases to rise and the temperature does rise is well established.
3. A small amount of steam leaked through my high-temperature epoxy around the thermocouple.

So in principle, this was a successful test.

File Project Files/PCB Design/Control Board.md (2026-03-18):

# Bio-Char Control Board v0.3.0

**ESP32-H2 Based Industrial Control System for Bio-Char Production**

---

## 📋 Overview

The Bio-Char Control Board is an industrial-grade PCB designed to control and monitor bio-char production processes. It features WiFi/Bluetooth connectivity, multi-voltage power management, high-power output control, and sensor interfaces.

### Key Features
- **ESP32-H2 Microcontroller** - WiFi 802.11n + Bluetooth 5.2
- **Multi-Voltage Power System** - 12V input, regulated 5V and 3.3V rails
- **High-Power Output Control** - 2× Solenoid valves, 2× SSR outputs
- **Sensor Interfaces** - K-type thermocouple, analog pressure sensor
- **Manual Override** - Physical switches for safety
- **Professional Design** - 2-layer PCB, through-hole components for easy assembly

---

## 🔧 Hardware Specifications

### Power Supply
- **Input:** 12V DC (via Phoenix terminal block)
- **5V Rail:** R-78E5.0-1.0 switching regulator (1A, 95% efficiency)
- **3.3V Rail:** ESP32-H2 internal LDO
- **Protection:** 2A PTC resettable fuse, reverse polarity protection

### Microcontroller
- **IC:** Espressif ESP32-H2-DEVKITM-1-N4
- **Connectivity:** WiFi 802.11b/g/n (2.4GHz), BLE 5.2, Thread/Zigbee capable
- **Flash:** 4MB
- **RAM:** 272KB SRAM
- **Processor:** RISC-V 96MHz

### Output Control
- **Solenoid Valves:** 2× IRLB3813PBF N-channel MOSFETs (30V, 100A, 2.3mΩ)
- **SSR Control:** 2× NPN transistor drivers (2N3904)
- **Protection:** Flyback diodes on all inductive loads

### Sensor Interfaces
- **Thermocouple:** MAX31855 breakout module (K-type, -200°C to +700°C, SPI)
- **Pressure Sensor:** Analog input with voltage divider (0-5V → 0-3.3V)

### Connectors
- **Phoenix Contact Terminals:** 5.08mm pitch, 90° horizontal
  - 1× 3-position (pressure sensor)
  - 5× 2-position (power input, solenoids, SSRs)
- **Pin Headers:** 2.54mm pitch
  - 1× 8-pin (general I/O)
  - 1× 6-pin (MAX31855 interface)

---

## 📦 Bill of Materials (BOM)

**Complete BOM available:** [`Bio_Char_BOM_Mouser_FINAL.xlsx`](Bio_Char_BOM_Mouser_FINAL.xlsx)

### BOM Summary
- **Total Component Types:** 18
- **Total Components:** 40 items
- **Total Cost:** $48.12 (verified Mouser pricing as of March 2026)
- **Supplier:** Mouser Electronics

### Key Components

| Category | Component | Part Number | Qty | Unit Price |
|---|---|---|-----|---|
| **Microcontroller** | ESP32-H2-DEVKITM-1-N4 | 356-ESP32H2DKITM1-N4 | 1 | $9.38 |
| **Power** | R-78E5.0-1.0 Regulator | 919-R-78E5.0-1.0 | 1 | $3.97 |
| **Power** | Polyfuse 2A | 530-0ZRN0200FF1E | 1 | $0.42 |
| **MOSFETs** | IRLB3813PBF | 942-IRLB3813PBF | 2 | $2.16 |
| **Transistors** | 2N3904BU | 512-2N3904BU | 2 | $0.28 |
| **Diodes** | 1N4001RLG | 863-1N4001RLG | 2 | $0.13 |
| **Diodes** | 1N4148 | 512-1N4148 | 2 | $0.10 |
| **Diodes** | 1N5819RLG | 863-1N5819RLG | 1 | $0.39 |
| **Resistors** | 1kΩ 1/4W | 603-CFR-25JR-521K | 6 | $0.18 |
| **Resistors** | 100kΩ 1/4W | 603-CFR-25JB-52-100K | 4 | $0.18 |
| **Resistors** | 10kΩ 1/4W | 603-CFR-25JB-52-10K | 2 | $0.10 |
| **Resistors** | 22kΩ 1/4W | 603-CFR-25JB-52-22K | 2 | $0.10 |
| **Capacitors** | 100nF Ceramic | 80-C322C104K5R5TA | 3 | $0.87 |
| **Capacitors** | 47µF 25V Electrolytic | 598-476CKH025M | 2 | $0.21 |
| **Terminals** | Phoenix 2-pos 5.08mm | 651-1715721 | 5 | $1.30 |
| **Terminals** | Phoenix 3-pos 5.08mm | 651-1715734 | 1 | $1.66 |
| **Headers** | Pin Headers 2.54mm | 649-1012937990801BLF | 2 | $0.14 |
| **Modules** | MAX31855 Breakout | 485-269 | 1 | $14.95 |

**Note:** MOSFET upgrade from IRLB8721PBF to IRLB3813PBF provides better performance (lower Rds(on), higher current rating).

---

## 📐 PCB Specifications

### Physical Dimensions
- **Board Size:** TBD (verify in KiCad)
- **Layers:** 2 (Top + Bottom copper)
- **Thickness:** 1.6mm standard FR4
- **Copper Weight:** 1oz (35µm)

### Design Rules
- **Minimum Track Width:** 0.25mm (signal), 2.0mm (power)
- **Minimum Clearance:** 0.25mm
- **Via Size:** 0.6mm drill, 1.0mm pad (standard)
- **Surface Finish:** HASL or ENIG recommended

### Manufacturing Files
All necessary manufacturing files are included in this repository:
- **Gerber Files/** - Complete gerber set for PCB fabrication
- **Drill Files/** - NC drill files for hole placement

---

## 🔌 Pin Assignments

### ESP32-H2 GPIO Mapping

| GPIO | Function | Connection | Notes |
|---|---|---|---|
| GPIO0 | Solenoid 1 Control | Q2 base (via R1) | Drive Q1 MOSFET |
| GPIO1 | Solenoid 2 Control | Q5 base (via R7) | Drive Q3 MOSFET |
| GPIO2 | SSR1 Control | Direct output | Via current limit R3 |
| GPIO3 | SSR2 Control | Direct output | Via current limit R9 |
| GPIO4 | ADC Input | Pressure sensor | Via voltage divider R14/R15 |
| GPIO5 | MAX31855 CS | SPI Chip Select | Thermocouple interface |
| GPIO6 | MAX31855 CLK | SPI Clock | Thermocouple interface |
| GPIO7 | MAX31855 DO | SPI Data Out | Thermocouple interface |
| TBD | Manual Override 1 | Switch SW1 | Optional solenoid 1 |
| TBD | Manual Override 2 | Switch SW2 | Optional solenoid 2 |

---

## ⚡ Power Distribution

### Power Tree
```
12V Input (J1)
  │
  ├─[F1: Polyfuse 2A]─┬─[D1: 1N4001RLG]─┬── +12V Rail
  │                   │                  │   (Solenoids, SSRs)
  │                   │                  │
  │                   │                  └── [U3: R-78E5.0-1.0 Input]
  │                   │                         │
  │                   └─[C6: 47µF 25V]          │
  │                                             │
  │                                             ├── 5V Rail
  │                                             │   ├── ESP32-H2 VCC
  │                                             │   └── MAX31855 VIN
  │                                             │
  │                                             └─[C7: 47µF 16V]
  │
  └── ESP32 LDO ───> 3.3V Rail (Internal peripherals)
```

### Current Budget
- **12V Rail:** ~3-4A max (solenoids + regulator input)
- **5V Rail:** ~1A max (ESP32 + MAX31855)
- **3.3V Rail:** ~500mA max (ESP32 internal)

---

## 🛠️ Assembly Instructions

### Component Placement Order
1. **Passive Components First:** Resistors, diodes, capacitors
2. **IC Sockets (if used):** For U1, U3 (optional)
3. **Power Components:** F1, D1, U3, Q1, Q3
4. **Signal Components:** Q2, Q5, remaining passives
5. **Connectors:** Phoenix terminals, pin headers
6. **Modules Last:** ESP32-H2, MAX31855 (after testing power rails)

### Soldering Tips
- Use temperature-controlled soldering iron (350°C)
- Start with low-profile components
- Double-check polarized components (diodes, electrolytic caps)
- Test power rails before installing ESP32 and MAX31855

### Testing Procedure
1. **Visual Inspection:** Check for solder bridges, cold joints
2. **Power Test:** Apply 12V, verify 5V output (no load)
3. **Current Test:** Measure idle current (<50mA expected)
4. **ESP32 Test:** Upload basic blink sketch
5. **Sensor Test:** Read MAX31855 and pressure sensor
6. **Output Test:** Test MOSFET switching with load

---

## 📂 Repository Structure

```
PCB Design/
├── Bio_Char_BOM_Mouser_FINAL.xlsx    # Bill of Materials
├── Control Board.kicad_sch            # Schematic
├── Control Board.kicad_pcb            # PCB Layout
├── Control Board.kicad_pro            # Project File
├── Control Board.kicad_prl            # Local Settings
├── Control Board.md                   # This file
├── Gerber Files/                      # Manufacturing Files
│   ├── F_Cu.gbr                       # Top Copper
│   ├── B_Cu.gbr                       # Bottom Copper
│   ├── F_Mask.gbr                     # Top Soldermask
│   ├── B_Mask.gbr                     # Bottom Soldermask
│   ├── F_Silkscreen.gbr               # Top Silkscreen
│   ├── B_Silkscreen.gbr               # Bottom Silkscreen
│   ├── Edge_Cuts.gbr                  # Board Outline
│   └── ...                            # Additional layers
└── Drill Files/                       # Drill Files
    └── ...                            # NC drill files
```

---

## 🚀 Getting Started

### Prerequisites
- KiCad 9.0 or later
- Basic understanding of electronics
- Soldering equipment
- 12V DC power supply

### Ordering PCBs
1. Download gerber files from `Gerber Files/` folder
2. Upload to PCB manufacturer (JLCPCB, PCBWay, OSH Park, etc.)
3. Recommended settings:
   - Layers: 2
   - Thickness: 1.6mm
   - Copper: 1oz
   - Surface Finish: HASL or ENIG
   - Soldermask: Green (or your preference)

### Ordering Components
1. Open `Bio_Char_BOM_Mouser_FINAL.xlsx`
2. All Mouser part numbers are verified and ready to order
3. Total cost: ~$48 (as of March 2026)
4. Order from: [Mouser Electronics](https://www.mouser.com)

---

## 🔍 Design Decisions

### Why ESP32-H2?
- Native WiFi and Bluetooth connectivity
- Thread/Zigbee support for future smart home integration
- Adequate GPIO for all control and sensing needs
- Low power consumption
- Active community support

### Why Through-Hole Components?
- Easier hand assembly for prototypes
- Better for educational purposes
- More robust mechanical connections
- Easier to debug and repair
- Suitable for industrial environments

### Why IRLB3813PBF MOSFETs?
- Upgrade from original IRLB8721PBF
- Lower Rds(on) (2.3mΩ vs 8.7mΩ) = less heat
- Higher current rating (100A vs 62A) = more headroom
- Logic-level gate (works with 3.3V ESP32)
- Better availability

---

## ⚠️ Safety Considerations

### Electrical Safety
- **Input Fuse:** PTC resettable fuse provides overcurrent protection
- **Reverse Polarity:** D1 protects against reverse voltage
- **Flyback Protection:** Diodes on all inductive loads
- **Isolation:** Keep 12V and 3.3V circuits separated

### Operating Conditions
- **Temperature Range:** 0°C to 60°C ambient
- **Humidity:** <85% RH (non-condensing)
- **Ventilation:** Ensure adequate airflow around regulator

### Installation
- Use proper gauge wire for 12V input (18 AWG minimum)
- Secure all screw terminals tightly
- Mount board in protective enclosure
- Keep away from moisture and extreme temperatures

---

## 📝 Version History

### v0.3.0 (March 2026) - Current
- Complete PCB layout with routing
- Verified BOM with Mouser pricing
- Manufacturing files (Gerbers + Drills) generated
- MOSFET upgrade to IRLB3813PBF
- Comprehensive documentation

### v0.2.0
- Schematic refinement
- Component selection and footprint assignment

### v0.1.0
- Initial schematic design
- Basic architecture
---

## 👤 Author

**hardhik03**
- GitHub: [@hardhik03](https://github.com/hardhik03)

---

**Last Updated:** March 18, 2026  
**KiCad Version:** 9.0.7  
**Board Revision:** v0.3.0

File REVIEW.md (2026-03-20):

# Project Review: Biochar Toilet Prototype

## 1. Project Summary

**Goal:** Develop a low-cost, low-energy Biochar Toilet capable of quickly reducing human waste to sanitary biochar, primarily targeting impoverished communities lacking sewage infrastructure.

**Methodology:**
- **Phase 1 (Current):** A prototype using a pressure cooker to validate the core physical processes: heating, pressurization, "flash" decompression for sterilization and cell destruction, and dryness detection.
- **Process:** The system seals the waste and heats it until a target pressure (e.g., 15 PSI) and temperature (e.g., 121°C) are reached. A valve then opens to "flash" the water into steam, sterilizing the sample. Once the sample is dry (detected when temperature rises without a corresponding pressure increase), it is further heated to charring temperatures.
- **Components:** The current system uses a pressure sensor, a thermocouple, a solid-state relay (SSR) for a hot plate, and a solenoid valve. The future design envisions an induction-heated, internally-fitting oval stainless steel pressure vessel with a magnetite catalyst.

## 2. Code Review (Bugs & Improvements)

The repository contains two main logic components: `valve_controller.py` and `dryness_monitor.py`, along with their respective test suites.

### A. Valve Controller (`valve_controller.py`)
- **Status:** The `README.md` and `TODO.md` mention a "small bug controlling the valve."
- **Analysis:**
  - The `update(pressure, temperature)` method checks if `pressure >= self.target_pressure` AND `temperature >= self.target_temperature` to set `self.valve_open = True`.
  - **Bug/Issue:** The latching logic is implemented correctly (once open, it stays open unless `reset()` is called). However, the logic requires *both* pressure and temperature to meet or exceed targets simultaneously. In a real physical system, if the pressure hits 15 PSI before the temperature reaches 121°C, or vice-versa, the valve might not open when intended. Furthermore, the "flash" decompression relies on rapid pressure drop, but if the valve opens and pressure drops, it remains latched open (as intended for flashing), but there is no logic to *close* the valve again after flashing to build pressure for a subsequent cycle or for charring.
  - **Improvement:** The controller likely needs a more complex state machine (e.g., `HEATING`, `FLASHING`, `DRYING`, `CHARRING`) rather than a simple boolean `valve_open` latch. It needs a mechanism to close the valve after a set time or when pressure drops below a safe threshold.

### B. Dryness Monitor (`dryness_monitor.py`)
- **Status:** Implements logic to detect dryness based on diverging temperature and pressure trends.
- **Analysis:**
  - The `is_dry()` method calculates rates over a sliding window (`history`).
  - **Bug/Issue:** The rate calculation uses `end['time'] - start['time']`. However, if `add_reading` is called rapidly with the same timestamp, it could cause a division by zero. The code currently checks `if time_diff <= 0: return False`, which prevents the crash but silently ignores the readings.
  - **Bug/Issue:** The rate calculation is highly sensitive to the window size (`history_len`). If `history_len=10` and readings are taken every millisecond, the time window is only 10ms, making the rate calculation extremely noisy. The tests simulate readings 1 second apart, but real sensor data might be faster and noisier.
  - **Improvement:** Consider using a moving average or a low-pass filter for temperature and pressure before calculating the derivative. Also, ensure timestamps are strictly monotonically increasing or enforce a minimum time delta between recorded readings.

## 3. Design Review (Mechanics & Safety)

The design concepts outlined in `DESIGN_IDEAS.md` and modeled in `pressure_vessel.scad` show significant thought towards industrial robustness.

### A. Pressure Vessel Architecture
- **"Inside-Fitting" Oval Manway:** This is an excellent, proven design for pressure vessels. It naturally uses internal pressure to enhance the seal and eliminates complex locking mechanisms that could foul with dust. The addition of a single internal hinge for semi-automation is a practical refinement.
- **"Potted" Internal Coil:** Moving the induction coil inside the vessel (cast in high-temp refractory cement) solves the Faraday Cage effect and prevents the steel shell from overheating. This is a critical and sound design choice.

### B. Catalyst & Exhaust System
- **Magnetite Catalyst:** Using magnetite for both CO oxidation and De-NOx (SCR) using the ammonia naturally present in urine is highly innovative.
- **Heated "Reaction Tower":** Placing the catalyst in a vertical tower above the steam cleaning valve, heated by a central cartridge heater, is an efficient way to ensure the exhaust gases reach the necessary reaction temperatures (~350°C+).

### C. Safety Concerns & Considerations
- **Pop-off Valve:** The `TODO.md` correctly identifies the need for an emergency pop-off valve. The `pressure_vessel.scad` includes a "Pressure Relief Valve" on the lid, which is crucial. This must be a mechanical, fail-safe valve, completely independent of the software or microcontroller.
- **High-Amperage Feedthrough:** Routing high-power induction coil connections through a pressurized, wet, and chemically aggressive environment (urine/steam) is a major engineering challenge. The feedthroughs must be hermetically sealed, electrically isolated, and capable of withstanding thermal cycling. The `.scad` model shows side ports for this, overriding earlier ideas of lid routing.
- **Condenser/Containment:** The `README.md` notes that flashing steam must enter a separate containment chamber to cool and liquefy safely. This is vital to prevent scalding operators.

## 4. Next Steps & Recommendations

Based on the review, the immediate next steps should be:

1. **Fix the Valve Controller:** Refactor `valve_controller.py` to handle the full cycle (Heating -> Flashing -> Closing -> Charring). Implement a state machine rather than a simple latch.
2. **Robustify Dryness Monitor:** Add low-pass filtering to `dryness_monitor.py` to handle real-world sensor noise and ensure it handles high-frequency data sampling gracefully.
3. **Implement Heater Controller:** As per `TODO.md`, create the logic to control the solid-state relay (SSR) based on the dryness state (e.g., switch from boiling/flashing power levels to charring power levels).
4. **Mechanical Prototyping:** Build a physical prototype of the "Inside-Fitting" oval manway to test the seal under low pressure, before introducing the complexities of the internal induction coil.
5. **Implement Emergency Pop-off Safety Logic:** While the pop-off valve is mechanical, the software should also have a hard-stop safety threshold that cuts power to all heaters if pressure approaches the pop-off limit.

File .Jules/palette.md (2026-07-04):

## 2024-05-18 - Added keyboard accessibility to presentation deck
**Learning:** The presentation deck had a `#present-btn` that only indicated its action via a FontAwesome icon (`<i class="fa-solid fa-desktop"></i>`). While there was text "Present", screen readers could get confused by the icon without `aria-hidden="true"`. Furthermore, when switching to presentation mode, there was no shortcut hint. Adding `aria-label` and `title` to the button and dynamically updating them via JavaScript improves both screen reader experience and regular mouse/keyboard accessibility by exposing the `(Esc)` hint. Also added `:focus-visible` to interactive elements to help keyboard navigators, matching the color theme (`#B89E6B`).
**Action:** Always add `aria-hidden="true"` to pure decorative FontAwesome icons, add `aria-label`/`title` tooltips for action buttons, and remember to update `aria-label` state via JavaScript for toggle buttons. Ensure `:focus-visible` outlines match the design system's accent color.
## 2026-06-16 - Presentation Mode Keyboard UX
**Learning:** In custom presentation modes triggered by a button click, leaving focus on the button causes spacebar navigation to double-trigger the click event, exiting the mode. Also, default keyboard events (like Space or Arrows) can cause unwanted scrolling if not prevented.
**Action:** Use `.blur()` on toggle buttons after activation if the mode radically alters the UI, and add `e.preventDefault()` in keyboard navigation listeners for custom UI states.

## 2024-03-24 - Custom Presentation UX Feedback
**Learning:** When building custom HTML presentation decks (like `Biochar_Toilet_Slide_Deck.html`), native browser progress and navigation cues are lost. Adding a fixed visual progress bar with ARIA progressbar roles, and updating fullscreen toggle buttons' `title` and `aria-label` to explicitly list keyboard shortcuts (e.g. Space/Arrows), significantly improves the discoverability of navigation and overall screen reader accessibility.
**Action:** Always include an ARIA-enabled progress indicator for multi-step or paginated custom UI views, and explicitly state hidden keyboard navigation shortcuts in the ARIA labels of the UI controls that initiate those views.

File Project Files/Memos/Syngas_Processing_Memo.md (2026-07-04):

# Syngas Processing Memo: Advanced Phase 3 Considerations

**Note:** This is an advanced Phase 3 idea regarding catalytic and gas management incorporated directly into the biochar mixture and ceramic liner design considerations.

## Syngas to CO₂ Conversion Pathways

Syngas exiting your Downdraft Silicon Carbide (SiC) choke point consists primarily of Carbon Monoxide (CO), Hydrogen (H₂), and trace Methane (CH₄). To convert this into Carbon Dioxide (CO₂), we will focus on the most practical engineering pathway for a decentralized appliance.

### Catalytic Oxidation (Lean Combustion)

To maximize reliability and minimize system complexity, you can oxidize the syngas.

*   **The Chemistry:** Introduce a controlled amount of ambient air or pure oxygen to the syngas stream as it passes over an oxidation catalyst (or just a secondary combustion chamber).
*   **The Equations:**
    *   `2CO + O₂ → 2CO₂`
    *   `2H₂ + O₂ → 2H₂O`
    *   `CH₄ + 2O₂ → CO₂ + 2H₂O`
*   **The Result:** The syngas burns clean, leaving you with only CO₂ and water vapor.
*   **System Synergy:** This is an exothermic (heat-generating) reaction. You can capture this waste heat to pre-heat your incoming waste or power a thermoelectric generator. Once the water vapor is condensed out, you have a pure CO₂ stream.

## Economic Analysis: Syngas Processing

When evaluating the cost-effectiveness of your Biochar Induction Toilet's exhaust processing, we must prioritize the rugged simplicity of thermal oxidation.

### Lean Combustion (The "Burn It" Route)

*   **Philosophy:** Maximize reliability, minimize parts, and reduce the system's overall electrical draw.
*   **CapEx (Capital Cost):** VERY LOW.
*   **Hardware:** Requires only an ambient air-injection valve (a venturi or small blower) right after the 1000°C SiC catalytic plug, plus a heat exchanger or Thermoelectric Generator (TEG).
*   **Complexity:** No exotic materials required beyond the existing high-temp plumbing.
*   **OpEx (Operational Cost):** NEGATIVE (Saves Money).
*   **Energy:** Burning syngas (CO, H₂, CH₄) is highly exothermic. By routing this waste heat via a heat exchanger back to the primary pyrolysis vessel, you drastically reduce the electrical load required by your primary induction coil.
*   **Maintenance:** Almost zero. There are no membranes to foul or salts to replace.
*   **ROI / Value:** The return on investment comes purely from energy efficiency (lower electricity bills) and extreme reliability, which lowers the lifetime maintenance cost of the toilet.

**The Engineering Verdict**

For a Household / Decentralized Appliance, Lean Combustion is the clear winner. Homeowners want a toilet that never breaks, has no odor, and doesn't spike their power bill. Capturing the heat to lower the induction coil's power draw makes this highly cost-effective and practical.

## Sulfur Mitigation: Protecting the Base Unit

In the Lean Combustion base model, our goal is to burn the syngas to recover heat. However, the H₂S present in fecal syngas poses a severe corrosion threat to heat exchangers (H₂SO₄).
To maintain the "rugged and cheap" philosophy, we must avoid complex liquid scrubbers and instead rely on solid-state chemical capture before the combustion phase.

### Strategy 1: In-Situ Fixation (The "Zero-Hardware" Route)

You are already investigating blending mineral additives (like magnetite and kaolinite) into the waste to passivate heavy metals. You can use this exact same mechanism to trap sulfur inside the biochar before it ever becomes a gas.

*   **The Chemistry (Iron):** Magnetite (Fe₃O₄) under reducing conditions (pyrolysis) will react directly with sulfur compounds to form stable, solid Iron Sulfide (FeS, pyrite/pyrrhotite phases).
    *   `Fe₃O₄ + 3H₂S + H₂ → 3FeS + 4H₂O`
*   **The Chemistry (Calcium):** By adding agricultural lime (Calcium Carbonate, CaCO₃, or Calcium Hydroxide, Ca(OH)₂) to your mineral blend, it calcines into Calcium Oxide (CaO). This acts as a powerful in-situ sulfur sponge.
    *   `CaO + H₂S → CaS + H₂O`

*   **The Engineering Value:**
    *   **CapEx:** $0. No additional plumbing or chambers required.
    *   **OpEx:** Pennies per batch. Lime and iron dust are incredibly cheap.
    *   **Result:** The sulfur is permanently locked into the solid biochar matrix as inert metal sulfides. The syngas exiting the bottom of your pot is significantly desulfurized natively.

### Strategy 2: The "Iron Sponge" Dry Scrubber (The Hardware Route)

If in-situ fixation isn't enough to protect your heat exchanger, you need a pre-combustion dry scrubber. The industry standard for cheap, low-tech biogas desulfurization is the "Iron Sponge."

*   **The Concept:** A simple, unheated steel canister placed inline between your SiC catalytic exhaust port and your combustion chamber.
*   **The Media:** It is filled with wood chips or steel wool coated in hydrated iron oxide (Fe₂O₃·H₂O).
*   **The Chemistry (Capture):** As the warm syngas passes through, the H₂S binds to the iron, stripping it from the gas stream.
    *   `Fe₂O₃ + 3H₂S → Fe₂S₃ + 3H₂O`
*   **The Chemistry (Regeneration):** The true beauty of the Iron Sponge is that it is passive to regenerate. When the toilet is offline, exposing the canister to ambient air (oxygen) converts the iron sulfide back into iron oxide, dropping out pure, elemental sulfur as a solid dust.
    *   `2Fe₂S₃ + 3O₂ → 2Fe₂O₃ + 6S` (Solid Elemental Sulfur)

*   **The Engineering Value:**
    *   **CapEx:** Very low. Just a sealed steel tube with basic mesh filters at both ends.
    *   **OpEx:** Minimal. The media lasts for months or years depending on regeneration cycles, and replacement media (iron-coated wood chips) is DIY-friendly and ultra-cheap.

### Strategy 3: The High-Temperature Ceramic/Magnetite Cartridge (The Choke Point Scrubber)

This strategy leverages the peak temperatures at the bottom of the induction vessel to maximize chemical reaction rates.

*   **The Concept:** A replaceable Silicon Carbide (SiC) and Magnetite cartridge located at the bottom of the pot, serving as the final "choke point" for the downdraft gas path.
*   **The Chemistry:** At temperatures exceeding 800°C, the reaction between H₂S and the concentrated magnetite in the cartridge becomes extremely efficient. The SiC matrix ensures the cartridge remains structurally sound and highly thermally conductive, staying at peak temperature throughout the cycle.
*   **The Engineering Value:**
    *   **Maximized Efficiency:** Concentrating the scrubbing media in the hottest zone of the reactor ensures that even refractory sulfur compounds are cracked and captured.
    *   **Hardware Protection:** By removing H₂S inside the primary vessel before it reaches the solenoid valve or the external heat exchanger, you virtually eliminate high-temperature sulfuric corrosion in your expensive plumbing.
    *   **Modularity:** The cartridge can be easily replaced during routine maintenance, similar to a ceramic oil filter.

### The Recommended Architecture

Combine all three for a "Zero-Corrosion" system.

1.  **In-Situ Fixation:** Dose waste with Lime/Magnetite to capture the bulk of the sulfur in the biochar.
2.  **High-Temp Cartridge:** Force the exiting syngas through the bottom SiC/Magnetite cartridge at 800°C+ to scrub the majority of the remaining H₂S.
3.  **Iron Sponge:** Use a small, passive external canister for final polishing and as a visual indicator of system health.
4.  **Clean Combustion:** Burn the purified syngas for heat recovery with zero risk to the heat exchanger.

This keeps the base unit virtually maintenance-free while drastically extending the lifespan of your thermal recovery hardware.

## Engineering Brief: Modular Ceramic Assembly & Baffle Tolerances

When designing the ceramic heat exchanger for the Biochar Induction Toilet, moving away from a monolithic (single-piece) cast to a modular assembly (separate inner wall, outer jacket, and baffle inserts) drastically reduces manufacturing complexity.

To answer the core question: **No, the internal baffles do not need to be air-tight against the walls. In fact, designing them with a slight "leaky" slip-fit is highly recommended.**

### 1. The "Leaky" Advantage: Thermal Decoupling

If you were to rigidly bond (or co-cast) the complex baffles directly to the inner and outer walls, you would create a thermal time bomb.

*   **Differential Expansion:** The inner wall facing the induction susceptor will be hundreds of degrees hotter than the outer insulating jacket.
*   **Thermal Shear:** If the baffles connect these two walls with a rigid, air-tight seal, the inner wall will expand more than the outer wall, placing massive shear stress on the baffles until they snap.
*   **The Slip-Fit Solution:** By allowing the baffle insert to sit loosely (with a tolerance gap of a few millimeters) between the inner and outer jackets, the components can expand and contract independently. A "leaky" mechanical fit prevents catastrophic thermal cracking.

### 2. Managing Fluid Dynamics (The Path of Least Resistance)

The trade-off of a leaky seal is fluid dynamics. Gases will always take the path of least resistance.

*   **The Risk:** If the gap between your active ceramic sponge/baffles and the smooth wall is too large, the venturi will pull the hot gases straight up the smooth gap, bypassing the heat-transferring matrix entirely.
*   **The Mitigation (Labyrinth Edges):** You do not need a chemical seal, but you do need a tortuous path. You can design the outer edge of your baffle inserts with interlocking steps, or simply wrap the edges of the ceramic sponge in a compressible high-temp ceramic fiber blanket (like Kaowool) before sliding it into the jacket. This acts as a soft, high-temp "piston ring" that forces the gas through the sponge without creating a rigid bond.

### 3. The Modular Architecture (Material Optimization)

Your proposal to use different materials for the separate components is exactly how industrial high-temperature reactors are built. This allows you to optimize each layer:

*   **The Inner Sleeve (Heat Transfer):** A simple, straight tube made of dense, high-thermal-conductivity ceramic, such as Silicon Carbide (SiC) or high-purity Alumina. It transfers heat efficiently but is easy to manufacture because it has no complex geometry.
*   **The Baffle/Sponge Insert (The Core):** A stackable series of complex Cordierite baffles or a cylinder of reticulated ceramic foam. This drops over the inner sleeve. Because it is separate, you can easily coat this specific part in your active sulfur-scrubbing washcoat.
*   **The Outer Jacket (Insulation):** A thick, simple tube made of highly insulating material, like porous mullite, zirconia, or a refractory castable. It contains the gas flow and protects the outer pressure vessel.

### 4. Manufacturing and Maintenance Value

*   **Reduced CapEx:** Creating a mold for a double-walled vessel with internal spiraling baffles is incredibly expensive and prone to casting defects. Casting three simple nested cylinders is cheap and highly repeatable.
*   **Serviceability:** If the active sponge eventually becomes fouled with ash or degraded by acid gases, the user can simply open the pressure vessel, pull out the modular sponge insert, and drop in a replacement cartridge, rather than replacing the entire ceramic assembly.

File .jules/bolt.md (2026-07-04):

## 2025-02-14 - HTML Presentation Deck Media Loading
**Learning:** Native `loading="lazy"` for images and `preload="none"` for `<video>` tags are highly effective, low-risk frontend performance patterns for large slide decks like `Presentations/Biochar_Toilet_Slide_Deck.html` that default to loading all assets synchronously. Avoiding lazy loading on above-the-fold content prevents LCP penalties while still saving bandwidth on below-the-fold media.
**Action:** Always verify if large media assets in HTML/React/Vue components are loaded synchronously and default to using native lazy loading/preloading attributes for anything off-screen. Use Playwright to visually assert that these HTML-level optimizations do not break the CSS styling or DOM structure.
## 2025-02-14 - Throttling Resize Events in Presentation Deck
**Learning:** In the `Biochar_Toilet_Slide_Deck.html` presentation, window resize event listeners that trigger DOM layout recalculations (like `scaleActiveSlide`) must be throttled to prevent layout thrashing and main-thread blocking. A simple `window.addEventListener('resize', scaleActiveSlide)` causes performance issues during window adjustments.
**Action:** When adding resize event listeners in vanilla JS frontend code, always use a `requestAnimationFrame` (or similar) throttle to ensure DOM updates are capped at the display refresh rate (e.g., ~60fps).
## 2025-02-14 - Caching repeated remote asset fetches during export
**Learning:** The offline export script (`Presentations/export_offline.py`) was repeatedly fetching the same remote CSS and font assets via `requests.get()` because the same URLs were referenced multiple times in the HTML and CSS. This caused the script to be significantly slower and waste network requests.
**Action:** When writing or optimizing scripts that fetch remote assets or read local files, always introduce a memory cache (e.g., a dictionary) to avoid redundant I/O operations for identical paths/URLs.

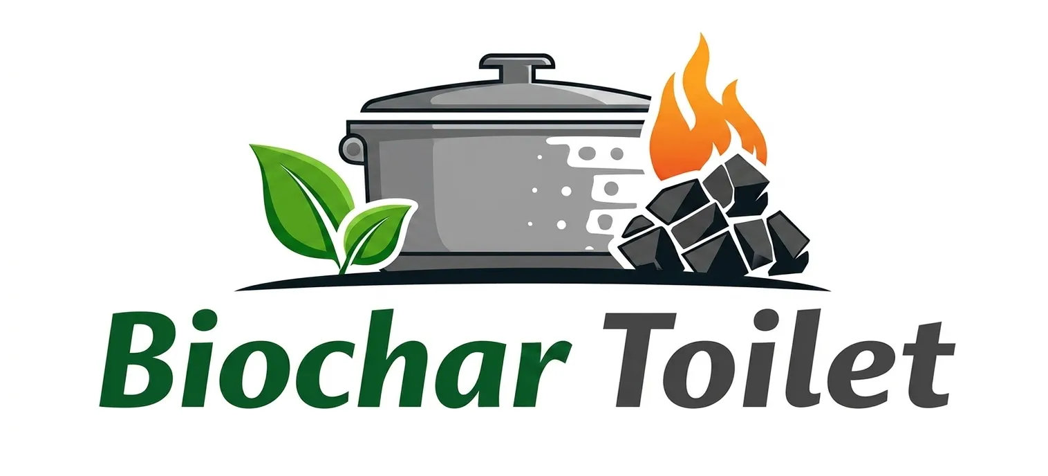
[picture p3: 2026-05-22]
images/s-blob-v1-IMAGE-u5mOaW5JDZ4.webp

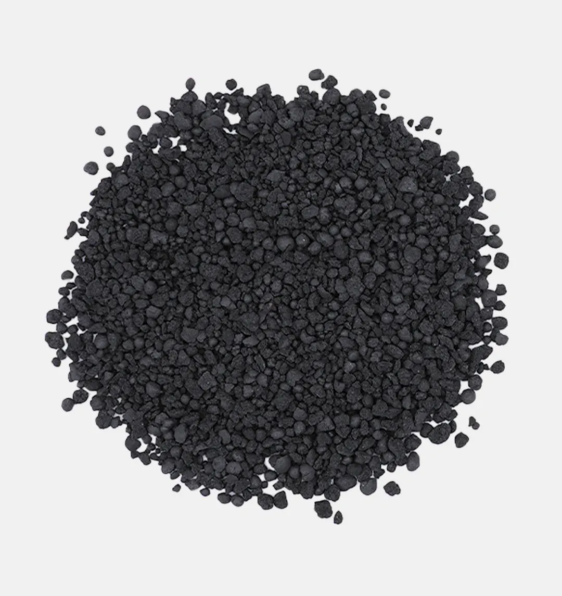
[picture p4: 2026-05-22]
images/image.webp

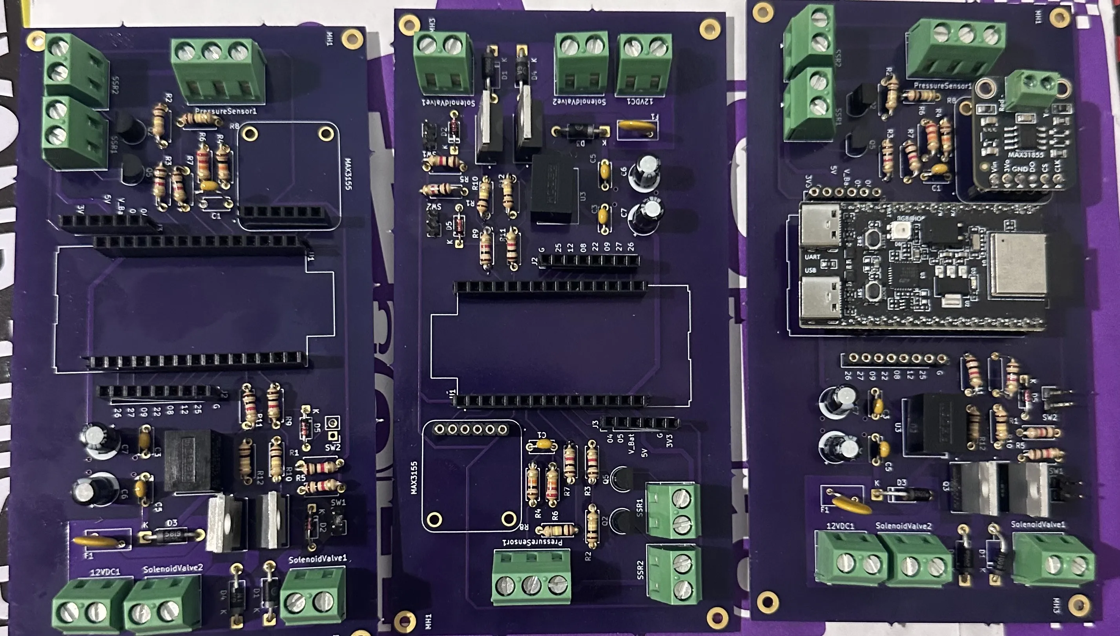
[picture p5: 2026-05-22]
images/PCB_Board.webp

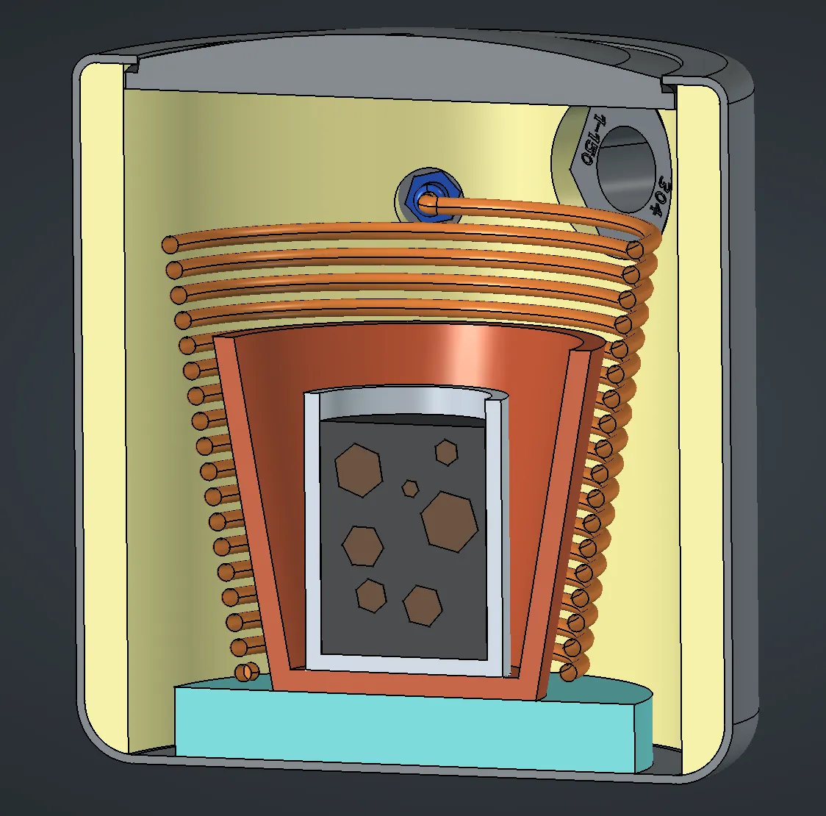
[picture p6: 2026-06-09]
images/coil_vessel_liner.webp

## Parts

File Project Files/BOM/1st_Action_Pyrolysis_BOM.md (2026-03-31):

| Index | Acquired | Nomenclature | Description | Order Link | Units | Cost | Total ( Pre-Tax) |
|---:|:---|:---|:---|:---|:---|---:|---:|
| 1 | [x] | Pressure Vessel: 12L (12.2qt) | Hawkins 12 Liter Classic Pressure Cooker, Best Inner Lid Cooker, Silver (CL412) | Amazon: Hawkins 12L Order Page | 1ea |  78.98 | 860.16 |
| 2 | [x] | Dual-Channel Thermocouple & Meter | Dual-Channel K/J Thermocouple Thermometer with 4 K-Type Thermocouples -328°F ~ 2501°F Measurement Range HVAC Temperature Meter Gauge with Data Hold, MAX/MIN/AVG, Hi/Lo Backlit Alarm, ADJ Compensation | Amazon: Dual-Thermocouple-Meter | 1ea |  28.99 | |
| 3 | [ ] | Ceramic Sheath: Thermocouple | High Temperature Ceramic Protection Tube Sheath for K-Type Thermocouple for Kiln Furnace for Pottery, Glass Fusing, Metal Working 8 inch Long | Amazon: Ceramic Sheath | 1ea |  25.99 | |
| 4 | [x] | High Heat Silicone Rubber | Mold Max 60 - High Heat Resistant Silicone Rubber Compound - Gallon Unit | Mold Max 60 - High Heat Resistant Silicone Rubber Compound - Gallon Uni | 1ea |  35.27 | |
| 5 | [x] | Heat Exchanger | Heat Exchanger | Heat Exchanger | 1ea |  43.09 | |
| 6 | [ ] | Hot Water Recirculating Pump | Hot Water Recirculating Pump, 93W, 110V Water Circulator Pump, Circulation Pump, 3/4″ G Thread to 1/2″ NPT Brass Adapter, Stainless Steel Head | Hot Water Recirculating Pump | 1ea |  43.99 | |
| 7 | [ ] | 2" Universal Catalytic Converter | 2" Universal Catalytic Converter | 2" Universal Catalytic Converter | 1ea | | |
| 8 | [ ] | High temp air filter | | | 1ea | | |
| 9 | [ ] | Coil stand-off | | | 1ea | | |
| 10 | [ ] | Crucible/fiberglass sack/bag | Holds, bentonite | | 1ea | | |
| 11 | [ ] | Electrical Insulation ¼” bulkhead | Induction coil ¼” passthrough bulkhead | | 1ea | | |
| 12 | [x] | Bentonite Clay Granules | Unscented Clumping Clay Cat Litter | Unscented Clumping Clay Cat Litter | 1ea | | |
| 13 | [x] | Black Iron Oxide - Fe3O4 | Black Iron Oxide - Fe3O4 - Natural - 5 Pounds | Black Iron Oxide - Fe3O4 | 1ea |  19.99 | |
| 14 | [ ] | Camera Pole Mount Bracket | Sumnacon Camera Pole Mount Bracket, 2 Pcs Stainless Steel Pole Mount | https://www.amazon.com/Sumnacon-Stainless-Brackets-Universal-Security/dp/B0DPJ1XPV8/ | 1ea | | |
| 15 | [ ] | Fuel Cell Bulkhead Adapter Fittings SUM-220682B | Fitting, Fuel Cell, Male Bulkhead, -6 AN, Aluminum, Black Anodized, Each | https://www.summitracing.com/parts/sum-220682b | 1ea |  11.99 | |
| 16 | [ ] | Chemical-Resistant Slippery PTFE Tube | 3/8" OD x 1/4" ID | https://www.mcmaster.com/8547K11/ | 1ea | 6.83 | |
| 17 | [ ] | McMaster-Carr Part 2227K62 | | https://www.mcmaster.com/2227K62/ | 1ea | | |
| 18 | [ ] | PTFE Plastic Washer | for Number 12 Screw Size, 0.250" ID, 0.562" OD | https://www.mcmaster.com/95630A898/ | 1ea | 8.86 | |
| 19 | [ ] | 304 SS Threaded Pipe Fitting | 304 SS Threaded Pipe Fitting, Tee Connector, 1 NPT Female | https://www.mcmaster.com/4464K53/ | 1ea |  15.46 | |
| 20 | [x] | MEAN WELL RSP-2400-48 AC to DC Power ... | MEAN WELL RSP-2400-48 AC to DC Power Supply | Amazon: MEAN WELL RSP-2400-48 | 1ea | 361.64 | |
| 21 | [x] | Beduan 1" Female Bulkhead Water Tank ... | Beduan 1" Female Bulkhead Water Tank Connector | Amazon: Beduan 1" Female Bulkhead | 1ea |  12.99 | |
| 22 | [x] | 1" Male Hex Nipple Pipe Fittings | 1" Male Hex Nipple Pipe Fittings | Amazon: 1" Male Hex Nipple | 1ea | 9.99 | |
| 23 | [x] | GOORY Copper Tubing 1/4" OD x 0.187" ... | GOORY Copper Tubing 1/4" OD x 0.187" ID x 50Ft | Amazon: GOORY Copper Tubing | 1ea |  63.99 | |
| 24 | [x] | 1800W 12V-48V ZVS Low Voltage DC Indu... | 1800W 12V-48V ZVS Low Voltage DC Induction Heater | Amazon: 1800W Induction Heater | 1ea |  66.99 | |
| 25 | [x] | Kidde Carbon Monoxide Detector | Kidde Carbon Monoxide Detector, Battery Powered | Amazon: Kidde Carbon Monoxide Detector | 1ea |  23.97 | |
| 26 | [x] | U.S. Solid 1" Solenoid Valve - Stainl... | U.S. Solid 1" Solenoid Valve - Stainless Steel | Amazon: U.S. Solid 1" Solenoid Valve | 1ea |  72.59 | |
| 27 | [ ] | uxcell 2mm Bearing Balls | uxcell 2mm Bearing Balls, 100 Pcs 440C Stainless Steel G10 | Amazon: uxcell 2mm Bearing Balls, 100 Pcs | 1ea | 6.99 | |
| 28 | [ ] | 100Pcs 3mm Diameter Steel Bike Bicycl... | 100Pcs 3mm Diameter Steel Bike Bicycle Bearing Ball Spares T3T5 | Amazon: 100Pcs 3mm Diameter Steel Bike Bearing Ball | 1ea | 3.99 | |
| 29 | [x] | uxcell 10000pcs 2mm Carbon Steel Bear... | uxcell 10000pcs 2mm Carbon Steel Bearing Balls G1000 Precision | Amazon: uxcell 10000pcs 2mm Carbon Steel Bearing Balls | 1ea |  13.29 | |
| 30 | [ ] | uxcell 10000pcs 1mm Carbon Steel Bear... | uxcell 10000pcs 1mm Carbon Steel Bearing Balls G1000 Precision | Amazon: uxcell 10000pcs 1mm Carbon Steel Bearing Balls | 1ea | 5.89 | |

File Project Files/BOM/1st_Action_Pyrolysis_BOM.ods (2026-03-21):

 | Pyro-T Project BOM: 1st Actionable Item: Achieve Pyrolysis
Index | Nomenclature | Description | Order Link | Units | Cost | Total ( Pre-Tax)
 | Pressure Vessel: 12L (12.2qt) | Hawkins 12 Liter Classic Pressure Cooker, Best Inner Lid Cooker, Silver (CL412) | Amazon: Hawkins 12L Order Page (https://www.amazon.com/dp/B00VNMLIZU/?th=1) | 1ea | $78.98 | $860.16
 | Dual-Channel Thermocouple & Meter | Dual-Channel K/J Thermocouple Thermometer with 4 K-Type Thermocouples -328°F ~ 2501°F Measurement Range HVAC Temperature Meter Gauge with Data Hold, MAX/MIN/AVG, Hi/Lo Backlit Alarm, ADJ Compensation | Amazon: Dual-Thermocouple-Meter (https://www.amazon.com/Landtek-Thermocouple-Thermometer-328-2501°F-Compensation/dp/B0C4YL76WY?s=industrial) | 1ea | $28.99
 | Ceramic Sheath: Thermocouple | High Temperature Ceramic Protection Tube Sheath for K-Type Thermocouple for Kiln Furnace for Pottery, Glass Fusing, Metal Working 8 inch Long | Amazon: Ceramic Sheath (https://www.amazon.com/Temperature-Ceramic-Protection-Thermocouple-Furnace/dp/B0CQTSTKYP) | 1ea | $25.99
 | High Heat Silicone Rubber | Mold Max 60 - High Heat Resistant Silicone Rubber Compound - Gallon Unit | Mold Max 60 - High Heat Resistant Silicone Rubber Compound - Gallon Uni (https://www.amazon.com/Mold-Max-60-Resistant-Silicone/dp/B09MJPZH22?th=1) | 1ea | $35.27
 | Heat Exchanger | Heat Exchanger | Heat Exchanger (https://www.amazon.com/Milageto-Condenser-Refrigerator-Exchanger-Industrial/dp/B0FHH1HCQW?th=1) | 1ea | $43.09
 | Hot Water Recirculating Pump | Hot Water Recirculating Pump, 93W, 110V Water Circulator Pump, Circulation Pump, 3/4″ G Thread to 1/2″ NPT Brass Adapter, Stainless Steel Head | Hot Water Recirculating Pump (https://www.amazon.com/VEVOR-Recirculating-Pump-93W-Circulating/dp/B09N92QGJD/?th=1) | 1ea | $43.99
 | 2" Universal Catalytic Converter | 2" Universal Catalytic Converter | 2" Universal Catalytic Converter (https://www.amazon.com/ASOPARTS-Universal-Catalytic-Converter-Outlet/dp/B0CMLWHZ7C/) | 1ea
 | High temp air filter |  |  | 1ea
 | Coil stand-off |  |  | 1ea
 | Crucible/fiberglass sack/bag | Holds, bentonite |  | 1ea
 | Electrical Insulation ¼” bulkhead | Induction coil ¼” passthrough bulkhead |  | 1ea
 | Bentonite Clay Granules | Unscented Clumping Clay Cat Litter | Unscented Clumping Clay Cat Litter (https://www.amazon.com/Dr-Elseys-Precious-Ultra-Litter/dp/B0009X0QSY/?th=1) | 1ea
 | Black Iron Oxide - Fe3O4 | Black Iron Oxide - Fe3O4 - Natural - 5 Pounds | Black Iron Oxide - Fe3O4 (https://www.amazon.com/Black-Iron-Oxide-Natural-Pounds/dp/B004KICAVU) | 1ea | $19.99
 | Camera Pole Mount Bracket | Sumnacon Camera Pole Mount Bracket, 2 Pcs Stainless Steel Pole Mount | https://www.amazon.com/Sumnacon-Stainless-Brackets-Universal-Security/dp/B0DPJ1XPV8/ | 1ea
 | Fuel Cell Bulkhead Adapter Fittings SUM-220682B | Fitting, Fuel Cell, Male Bulkhead, -6 AN, Aluminum, Black Anodized, Each | https://www.summitracing.com/parts/sum-220682b | 1ea
 | Chemical-Resistant Slippery PTFE Tube | 3/8" OD x 1/4" ID | https://www.mcmaster.com/8547K11/ | 1ea
 | McMaster-Carr Part 2227K62 |  | https://www.mcmaster.com/2227K62/ | 1ea
 | PTFE Plastic Washer | for Number 12 Screw Size, 0.250" ID, 0.562" OD | https://www.mcmaster.com/95630A898/ | 1ea
 | 304 SS Threaded Pipe Fitting | 304 SS Threaded Pipe Fitting, Tee Connector, 1 NPT Female | https://www.mcmaster.com/4464K53/ | 1ea
 | MEAN WELL RSP-2400-48 AC to DC Power ... | MEAN WELL RSP-2400-48 AC to DC Power Supply | Amazon: MEAN WELL RSP-2400-48 | 1ea
 | Beduan 1" Female Bulkhead Water Tank ... | Beduan 1" Female Bulkhead Water Tank Connector | Amazon: Beduan 1" Female Bulkhead | 1ea
 | 1" Male Hex Nipple Pipe Fittings | 1" Male Hex Nipple Pipe Fittings | Amazon: 1" Male Hex Nipple | 1ea
 | GOORY Copper Tubing 1/4" OD x 0.187" ... | GOORY Copper Tubing 1/4" OD x 0.187" ID x 50Ft | Amazon: GOORY Copper Tubing | 1ea
 | 1800W 12V-48V ZVS Low Voltage DC Indu... | 1800W 12V-48V ZVS Low Voltage DC Induction Heater | Amazon: 1800W Induction Heater | 1ea
 | Kidde Carbon Monoxide Detector | Kidde Carbon Monoxide Detector, Battery Powered | Amazon: Kidde Carbon Monoxide Detector | 1ea
 | U.S. Solid 1" Solenoid Valve - Stainl... | U.S. Solid 1" Solenoid Valve - Stainless Steel | Amazon: U.S. Solid 1" Solenoid Valve | 1ea
 | uxcell 2mm Bearing Balls | uxcell 2mm Bearing Balls, 100 Pcs 440C Stainless Steel G10 | Amazon: uxcell 2mm Bearing Balls, 100 Pcs | 1ea
 | 100Pcs 3mm Diameter Steel Bike Bicycl... | 100Pcs 3mm Diameter Steel Bike Bicycle Bearing Ball Spares T3T5 | Amazon: 100Pcs 3mm Diameter Steel Bike Bearing Ball | 1ea
 | uxcell 10000pcs 2mm Carbon Steel Bear... | uxcell 10000pcs 2mm Carbon Steel Bearing Balls G1000 Precision | Amazon: uxcell 10000pcs 2mm Carbon Steel Bearing Balls | 1ea
 | uxcell 10000pcs 1mm Carbon Steel Bear... | uxcell 10000pcs 1mm Carbon Steel Bearing Balls G1000 Precision | Amazon: uxcell 10000pcs 1mm Carbon Steel Bearing Balls | 1ea

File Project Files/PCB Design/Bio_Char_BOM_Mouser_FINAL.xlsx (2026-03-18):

Bio-Char Control Board - Mouser BOM
Item | Qty | References | Value | Description | Package/Footprint | Specifications | Manufacturer | MPN | Mouser PN | Unit Price | Ext Price | Notes
▼ CAPACITORS
1 | 3 | C1, C3, C5 | 100nF | Ceramic bypass capacitors | Disc 5.0mm | 50V, X7R, ±10% | Kemet | C322C104K5R5TA7305 | 80-C322C104K5R5TA | $0.87 | $2.61 | Input/Output & MAX31855 bypass
2 | 2 | C6, C7 | 47µF 25V | Aluminum electrolytic capacitors | Radial D6.3mm P2.5mm | 25V, 105°C (C7=16V covered) | Cornell Dubilier | 476CKH025M | 598-476CKH025M | $0.21 | $0.42 | U3 input/output filtering
▼ RESISTORS (All 1/4W, Through-Hole)
3 | 6 | R1,R3,R5,R7,R9,R11 | 1kΩ | Carbon film resistors 1/4W ±5% | Axial 7.62mm | 1/4W, ±5%, 1kΩ | YAGEO | CFR-25JR-52-1K | 603-CFR-25JR-521K | $0.18 | $1.08 | Current limit, base resistors
4 | 4 | R2,R8,R10,R12 | 100kΩ | Carbon film resistors 1/4W ±5% | Axial 7.62mm | 1/4W, ±5%, 100kΩ | YAGEO | CFR-25JB-52-100K | 603-CFR-25JB-52-100K | $0.18 | $0.72 | MOSFET pull-down resistors
5 | 2 | R4, R14 | 10kΩ | Carbon film resistors 1/4W ±5% | Axial 7.62mm | 1/4W, ±5%, 10kΩ | YAGEO | CFR-25JB-52-10K | 603-CFR-25JB-52-10K | $0.10 | $0.20 | Pull-up resistors
6 | 2 | R6, R15 | 22kΩ | Carbon film resistors 1/4W ±5% | Axial 7.62mm | 1/4W, ±5%, 22kΩ | YAGEO | CFR-25JB-52-22K | 603-CFR-25JB-52-22K | $0.10 | $0.20 | Voltage divider resistors
▼ DIODES
7 | 2 | D1, D4 | 1N4001RLG | Rectifier diodes 50V 1A | DO-41 P10.16mm | 50V, 1A, DO-41 | onsemi | 1N4001RLG | 863-1N4001RLG | $0.13 | $0.26 | SSR protection diodes
8 | 2 | D2, D5 | 1N4148 | Switching diodes 100V 150mA | DO-35 P7.62mm | 100V, 150mA, DO-35 | onsemi | 1N4148 | 512-1N4148 | $0.10 | $0.20 | Flyback protection diodes
9 | 1 | D3 | 1N5819RLG | Schottky diode 40V 1A | DO-41 P10.16mm | 40V, 1A Schottky | onsemi | 1N5819RLG | 863-1N5819RLG | $0.39 | $0.39 | Reverse polarity protection
▼ MICROCONTROLLER & POWER MANAGEMENT
10 | 1 | U1 | ESP32-H2-DEVKITM-1-N4 | WiFi/BLE development module | ESP32-H2 Module | 802.11n, BLE 5.2, 4MB Flash | Espressif | ESP32-H2-DevKitM-1-N4 | 356-ESP32H2DKITM1-N4 | $9.38 | $9.38 | Main microcontroller
11 | 1 | U3 | R-78E5.0-1.0 | 12V→5V 1A switching regulator | SIP-3 | 8-28V in, 5V 1A out, 95% eff | RECOM | R-78E5.0-1.0 | 919-R-78E5.0-1.0 | $3.97 | $3.97 | Buck converter (no heatsink needed)
12 | 1 | F1 | Polyfuse 2A | Resettable fuse PTC 2A | Radial | 2A hold, 4A trip | Bel | 0ZRN0200FF1E | 530-0ZRN0200FF1E | $0.42 | $0.42 | Overcurrent protection
▼ POWER & SIGNAL TRANSISTORS
13 | 2 | Q1, Q3 | IRLB3813PBF | N-channel MOSFETs | TO-220 | 30V, 100A, 2.3mΩ Rds(on) | Infineon | IRLB3813PBF | 942-IRLB3813PBF | $2.16 | $4.32 | ⚠️ Upgrade from IRLB8721 - Better!
14 | 2 | Q2, Q5 | 2N3904BU | NPN transistors | TO-92 | 40V, 200mA, hFE>100 | onsemi | 2N3904BU | 512-2N3904BU | $0.28 | $0.56 | MOSFET gate drivers
▼ CONNECTORS & TERMINALS
15 | 5 | 12V_I/P, Sol1, Sol2, SSR1, SSR2 | Terminal 2-pos | Phoenix terminal blocks 2-position | Phoenix 5.08mm | 2-pos, 5.08mm, 90°, 12A | Phoenix Contact | 1715721 | 651-1715721 | $1.30 | $6.50 | Power input & outputs
16 | 1 | PressureSensor1 | Terminal 3-pos | Phoenix terminal block 3-position | Phoenix 5.08mm | 3-pos, 5.08mm, 90°, 12A | Phoenix Contact | 1715734 | 651-1715734 | $1.66 | $1.66 | Pressure sensor connection
17 | 2 | J2, J3 | Pin Headers | Pin headers 2.54mm | 2.54mm vertical | 1x8 + 1x6, single row | Amphenol ICC | 10129379-908001BLF | 649-1012937990801BLF | $0.14 | $0.28 | I/O & MAX31855 connectors
▼ BREAKOUT MODULES
18 | 1 | MAX3155 | MAX31855 | Thermocouple amplifier breakout | Adafruit #269 | K-type, -200°C to +700°C, SPI | Adafruit | 269 | 485-269 | $14.95 | $14.95 | Thermocouple interface module
TOTAL COST: |  |  |  |  |  |  |  |  |  | $48.12 | $48.12

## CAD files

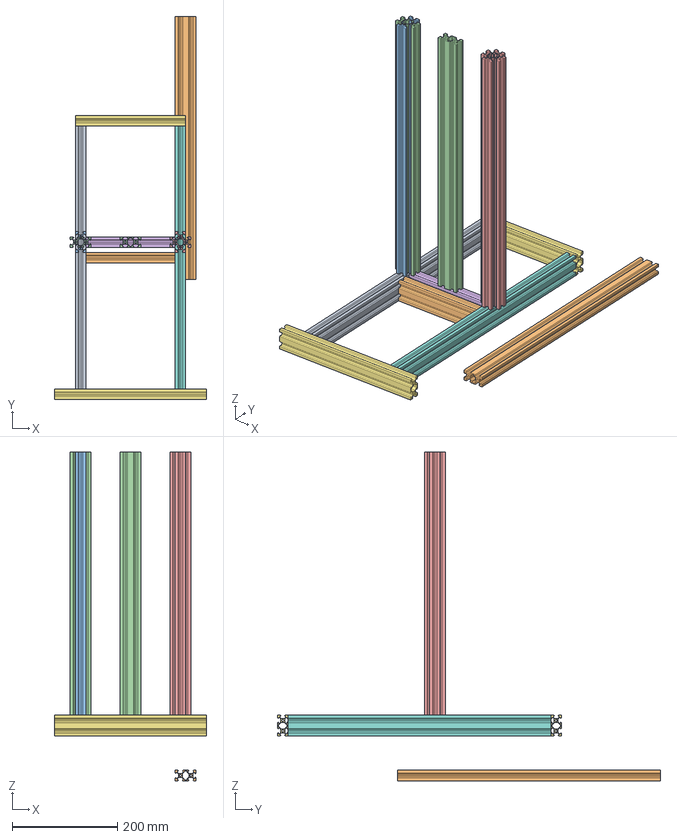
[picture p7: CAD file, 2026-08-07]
Project Files/CAD Files/Frame for Assembly_v2.2.FCStd
289.5 x 728.4 x 624.8 mm
20mmx40mm extruded aluminum
20mmx40mm extruded aluminum007
20mmx40mm extruded aluminum003
20mmx40mm extruded aluminum006
20mmx40mm extruded aluminum005
20mmx40mm extruded aluminum008
20mmx40mm extruded aluminum016
20mmx40mm extruded aluminum010
20mmx40mm extruded aluminum015
20mmx40mm extruded aluminum011
20mmx40mm extruded aluminum014
20mmx40mm extruded aluminum012
20mmx40mm extruded aluminum013
20mmx40mm extruded aluminum018
20mmx40mm extruded aluminum019
20mmx40mm extruded aluminum020

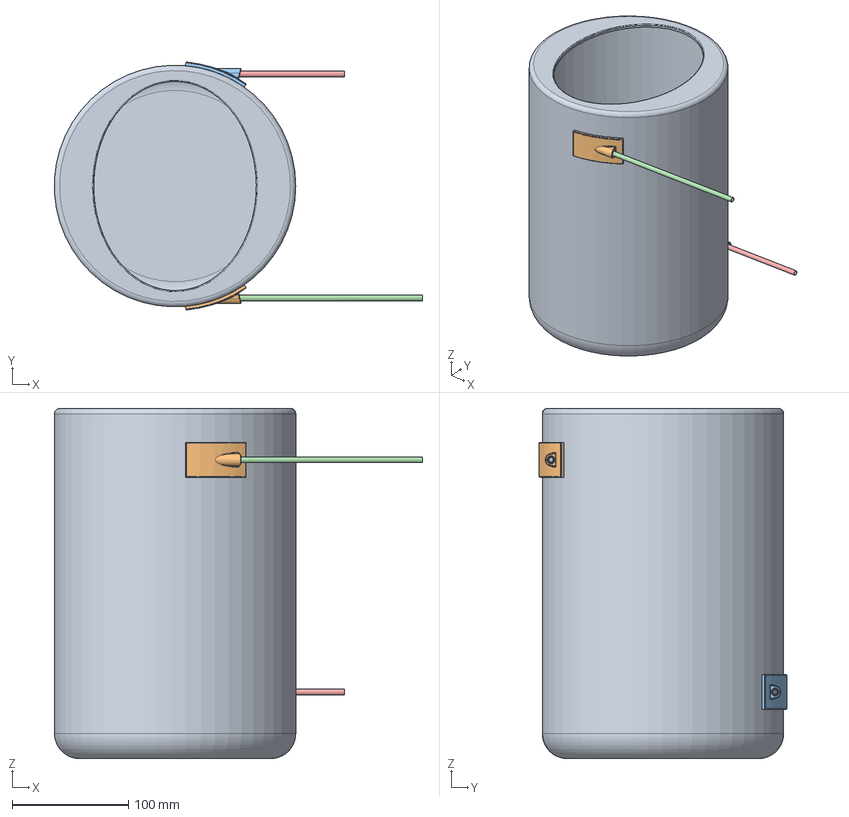
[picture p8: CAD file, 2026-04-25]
Project Files/CAD Files/Custom.concept.tangent.bulkhead.fitting/Custom tangent bulkhead fitting.FCStd
316.9 x 213.4 x 301.6 mm
Base
Custom Tangent fitting example001
Upper-Straight
Lower Straight

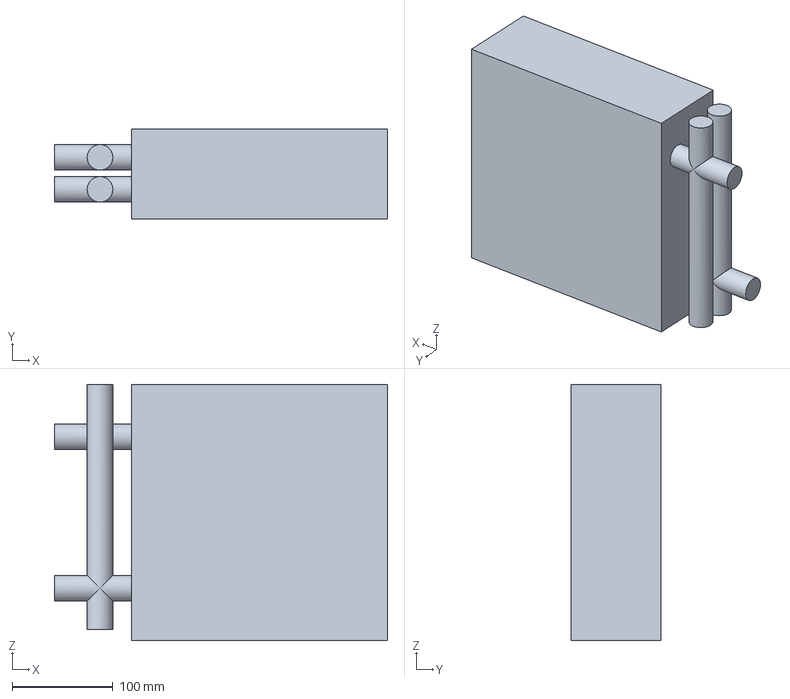
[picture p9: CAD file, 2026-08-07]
Project Files/CAD Files/Heat-Exchanger_HTL-10x10.FCStd
330.2 x 88.9 x 254.0 mm

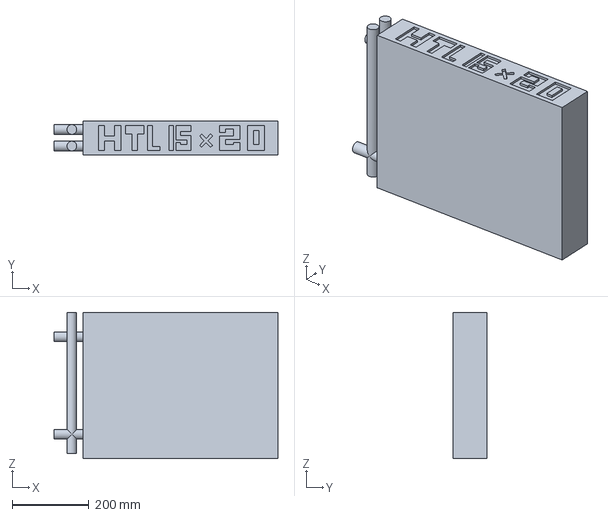
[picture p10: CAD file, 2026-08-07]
Project Files/CAD Files/Heat-Exchanger_HTL-15x20.FCStd
584.2 x 88.9 x 381.0 mm

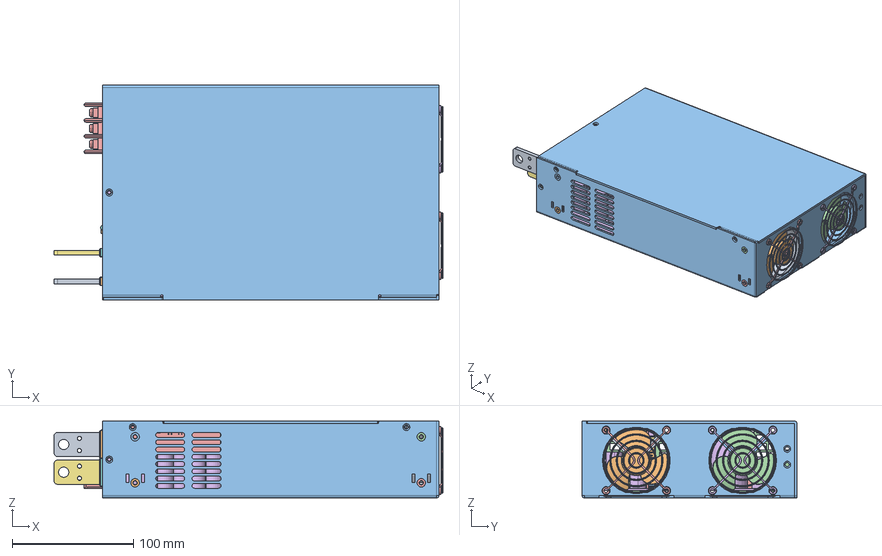
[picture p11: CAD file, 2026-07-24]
Project Files/CAD Files/RSP-2400-Mean_Well_PSU.FCStd
321.2 x 177.8 x 63.5 mm
FAN_4715KL40WB30_2
FAN
FAN_4715KL40WB30_001
FAN001
fan_a.1.1
fan_a.1.001
ff.1.1.1.1.1.1.2
ff.1.1.1.1.1.1.001
ff.1.1.1.1.1.1.002
ff.1.1.1.1.1.1.003
\S\JW\S\#\
M3-7L.1.2
M3-7L.1.001
ff.1.1.1.1.1.1.004
ff.1.1.1.1.1.1.005
ff.1.1.1.1.1.1.006
ff.1.1.1.1.1.1.007
ff.1.1.1.1.1.1.008
ff.1.1.1.1.1.1.009
ff.1.1.1.1.1.1.010
ff.1.1.1.1.1.1.011
M3-7L.1.002
M3-7L.1.003
M3-7L.1.004
M3-7L.1.005
M3-7L.1.006
\X2\02CB\X0\\S\0\S\[y
\S\/\S\%\S\#\.1
JJ.1
VR.1.1
VR.1.001
led.1.1.1
p1
p001
p2
p002
p003
p004
p005
p006
p007
p008
p009
p010
p011
p012
p013
VR.1.002
pcb2
pcb.1
CU1.1.2
GG.2.1.1
CU1.1.001
GG.2.1.001

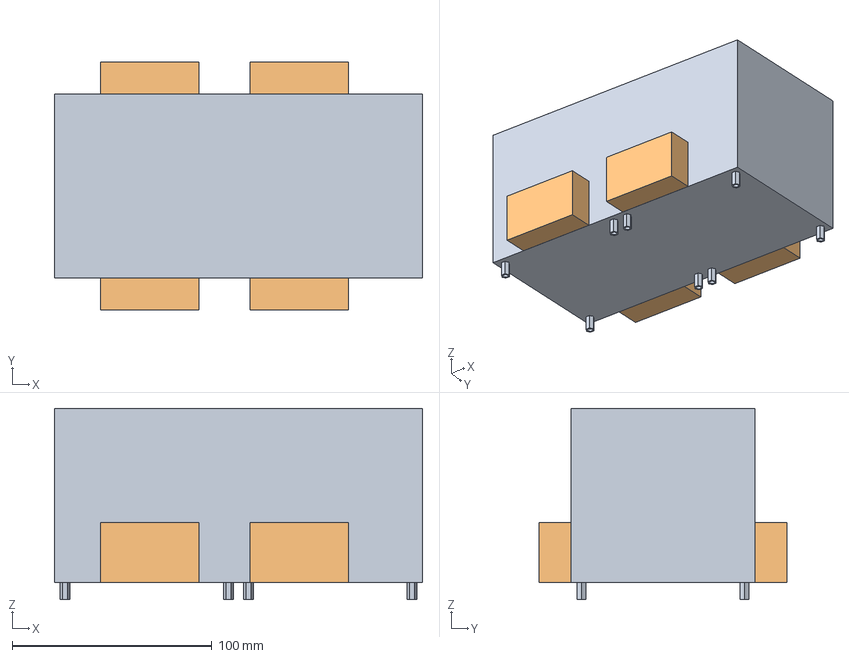
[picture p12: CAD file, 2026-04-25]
Project Files/CAD Files/Induction_Module_Clearance_model.FCStd
184.2 x 123.9 x 95.8 mm

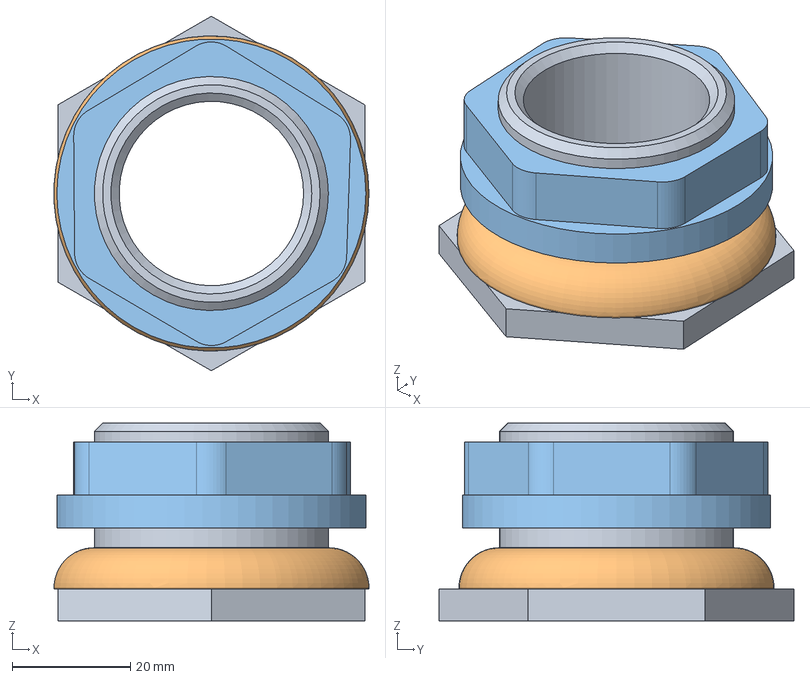
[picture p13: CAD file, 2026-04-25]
Project Files/CAD Files/1inID_304ss_bulkhead fitting.FCStd
53.3 x 60.0 x 33.5 mm
Seal

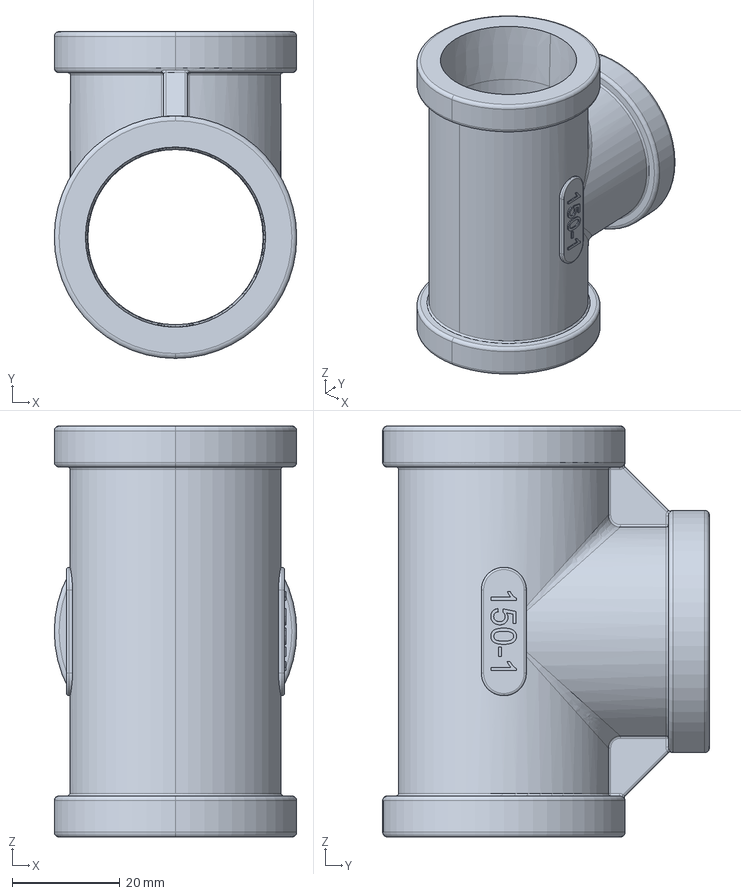
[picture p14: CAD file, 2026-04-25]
Project Files/CAD Files/4464K53_NO THREADS_304 Stainless Steel Threaded Pipe Fitting.FCStd
45.0 x 60.6 x 76.2 mm

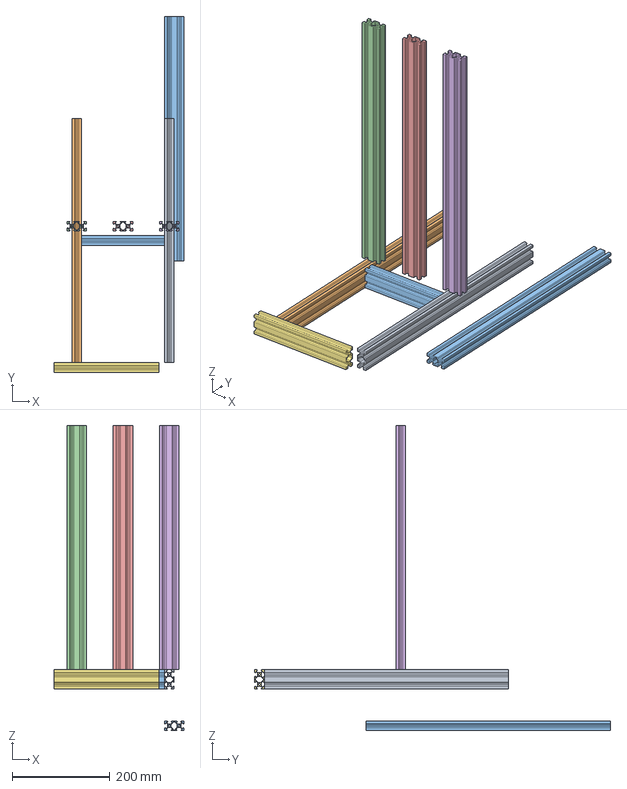
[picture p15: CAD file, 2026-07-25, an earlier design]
Project Files/CAD Files/Frame for Assembly_v2.1.FCStd
266.0 x 728.4 x 624.8 mm
20mmx40mm extruded aluminum
20mmx40mm extruded aluminum007
20mmx40mm extruded aluminum003
20mmx40mm extruded aluminum006
20mmx40mm extruded aluminum004
20mmx40mm extruded aluminum005
20mmx40mm extruded aluminum008

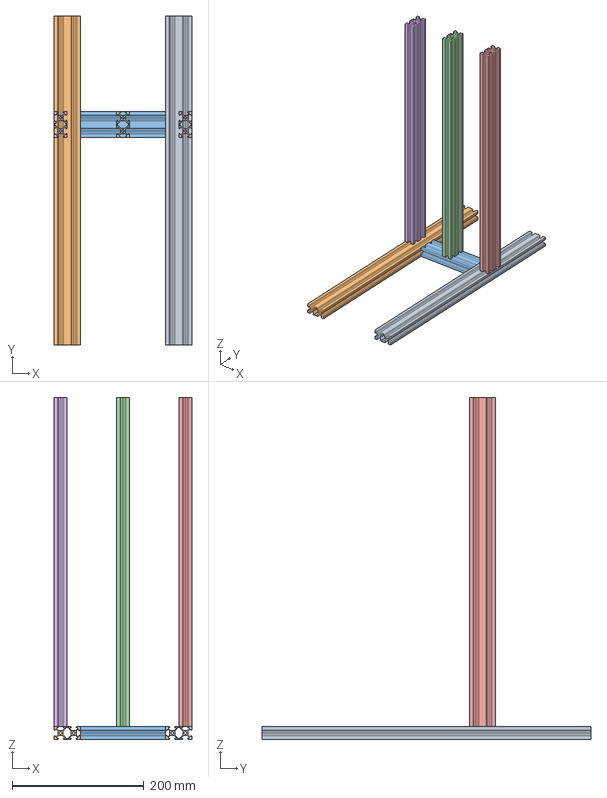
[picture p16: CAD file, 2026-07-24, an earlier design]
Project Files/CAD Files/Frame for Assembly_v2.0.FCStd
209.6 x 500.0 x 520.0 mm
20mmx40mm extruded aluminum
20mmx40mm extruded aluminum007
20mmx40mm extruded aluminum003
20mmx40mm extruded aluminum004
20mmx40mm extruded aluminum005
20mmx40mm extruded aluminum006

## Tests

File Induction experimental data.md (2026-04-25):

| Medium | Mass (g) | 0s | 10s | 20s | 30s | 40s | 50s | 60s | Final/Max | Notes |
|---|---|---|---|---|---|-----|-----|-----|---|---|
| Bentonite Clay | 5.01 | 78 | | 75.7 | 75 | 75  | 71  | 77  | 78 | No changes noted. |
| Magnetite | 5 | 81 | 88 | 96 | 200 | 330 | 590 | 740 | 740 | Stable ~700. |
| Graphene | 4.99 | 80 | 80 | 80 | 80 | 80  | 80  | 80  | 80 | No induction observed. |
| Graphite + Water  | 4.99g Graphite + water | 88 | 83 | 86 | 88 | 91  | 87  | 81  | 91 | Minimal fluctuation. |
| 1.2mm CS Bearings | 5.01 | 80 | 94 | 90 | 100 | 120 | 126 | 130 | 160 | Carbon Steel. |
| 1.2mm CS Bearings | Vol.* | 92 | 140 | 200 | 240 | 300 | 340 | 320 | 940 | *Equal volume to Magnetite. |
| Mixed Media* | Rough | 130 | 120 | 288 | 300 | 460 | 520 | 477 | 800 | *See extended data below. |
| Big System* | Mixed | 76 | 76 | 77 | 75 | 75  | â€” | â€” | â€” | Data cut off. |
| | | | | | | | | | | |
| | | | | | | | | | | |
| * extended data.  | | | | | | | | | | |
| Time (s) | Temp (°F) | Time (s) | Temp (°F) | Time (s) | Temp (°F) | | | | | |
| 80 | 520 | 130 | 740 | 180 | 730 | | | | | |
| 90 | 650 | 140 | 740 | 190 | 780 | | | | | |
| 100 | 690 | 150 | 760 | 200 | 800 | | | | | |
| 110 | 700 | 160 | 770 | 210 | 800 | | | | | |
| 120 | 720 | 170 | 760 | 220 | 740 | | | | | |

Core Thermocouple Probe Temperature: 717°F after extended run.

Mixed Media* :Nearly equal parts Magentite, bearings & Bentanite. (rough analysis)

Big System* :High wattage induction heater, larger crucible.

Quick Observations
The Magnetite Advantage: At 5 grams, the Magnetite is significantly more efficient at converting the induction field to heat compared to the same mass of Carbon Steel bearings (reaching 740°F vs 130°F in 60 seconds).

Volume vs. Mass: The Carbon Steel only starts to compete in peak temperature (940°F) when the volume is matched to the Magnetite, suggesting density and surface area are playing a massive role here.

The "Mixed" Thermal Inertia: The mixture shows a much more gradual and staggered climb, likely due to the Bentonite acting as a thermal buffer or insulator between the active heating elements.

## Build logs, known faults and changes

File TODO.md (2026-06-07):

# Project Tasks

Based on `README.md` and `DESIGN_IDEAS.md`.

- [x] Implement Valve Controller logic (to address the "small bug controlling the valve").
- [ ] Implement Heater Controller (mentioned as a future step).
- [ ] Design reaction vessel (ongoing).
- [ ] Implement emergency pop-off valve safety logic.

### Testing and Benchmarking Improvements
- [x] Fix lazy test `test_cooling_or_steady_temp` in `test_dryness_monitor.py` which only tests slow temperature rise instead of actual cooling (temperature dropping).
- [x] Fix lazy test `test_threshold_crossing` in `test_valve_controller.py` which only tests the boundary value exactly, instead of a true threshold crossing (transition from below to above threshold).
- [x] Add tests simulating noisy and high-frequency sensor data for `dryness_monitor.py` (rate calculation is highly sensitive to window size).
- [x] Develop tests and benchmarks for low-moisture samples (like the bread charring experiment) where the dryness algorithm failed to trigger due to lack of distinct pressure change.

Safety considerations:

We need to identify a safe opening temperature that we can open the lid

We should examine the component mix of materials safety, in addition at different temperatures and pressure, since our dynamic system covers a lot of different regions. 

We should consider opening the valve before the lid, allowing air into the system. 

We should wear PPE, respirator, eye protection, and heat resistant gloves. 

### Presentation Improvements
- [ ] Develop a snappy script for the presentation to keep the narrative engaging.
- [ ] Add story narrative slides to the presentation covering:
  - How the team conceived of the project.
  - The heat transfer difficulty discovered during Hardhik's experiment.
  - Lawrence's invention of the induction approach.
  - Progress and difficulties with charring things.

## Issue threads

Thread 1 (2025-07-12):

Chamber from Steel Pipe

ForrestErickson, 2025-07-12:
Asked an AI the question, "what length of 1 steel pipe for a volume of 50ml"

## The 1" Answer Summary

Therefore, a 1-inch Schedule 40 steel pipe would need to be approximately 3.53 inches long to hold a volume of 50 ml.

## The 1/2" Answer Summary

Therefore, a 1/2" Schedule 40 steel pipe needs to be approximately 10.07 inches long to hold a volume of 50ml.

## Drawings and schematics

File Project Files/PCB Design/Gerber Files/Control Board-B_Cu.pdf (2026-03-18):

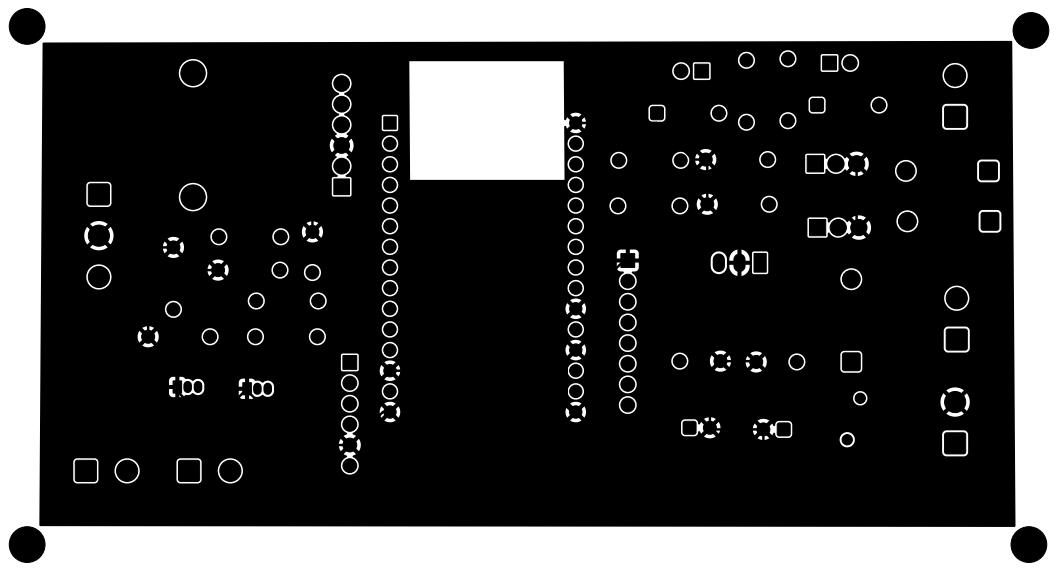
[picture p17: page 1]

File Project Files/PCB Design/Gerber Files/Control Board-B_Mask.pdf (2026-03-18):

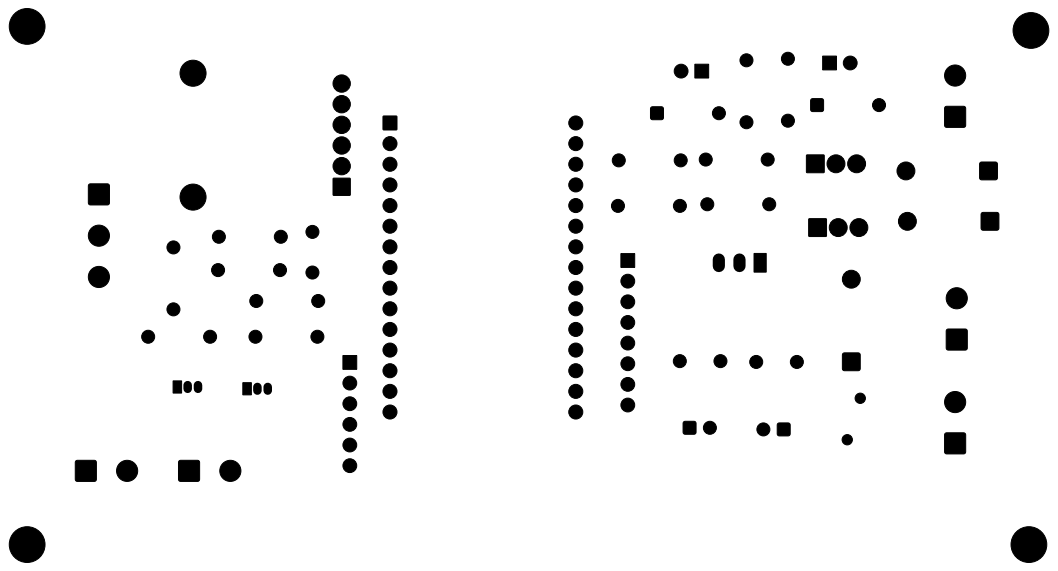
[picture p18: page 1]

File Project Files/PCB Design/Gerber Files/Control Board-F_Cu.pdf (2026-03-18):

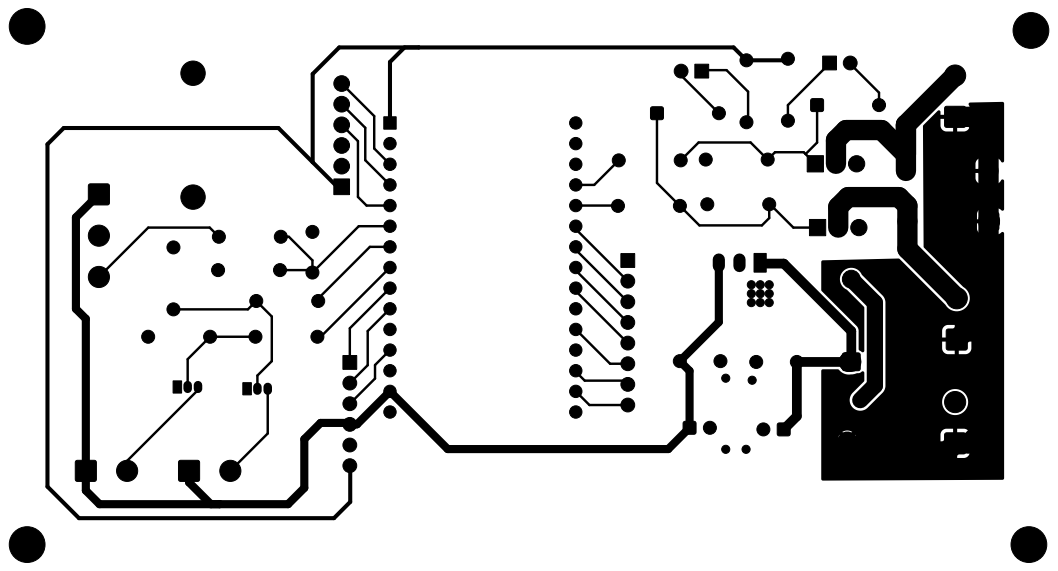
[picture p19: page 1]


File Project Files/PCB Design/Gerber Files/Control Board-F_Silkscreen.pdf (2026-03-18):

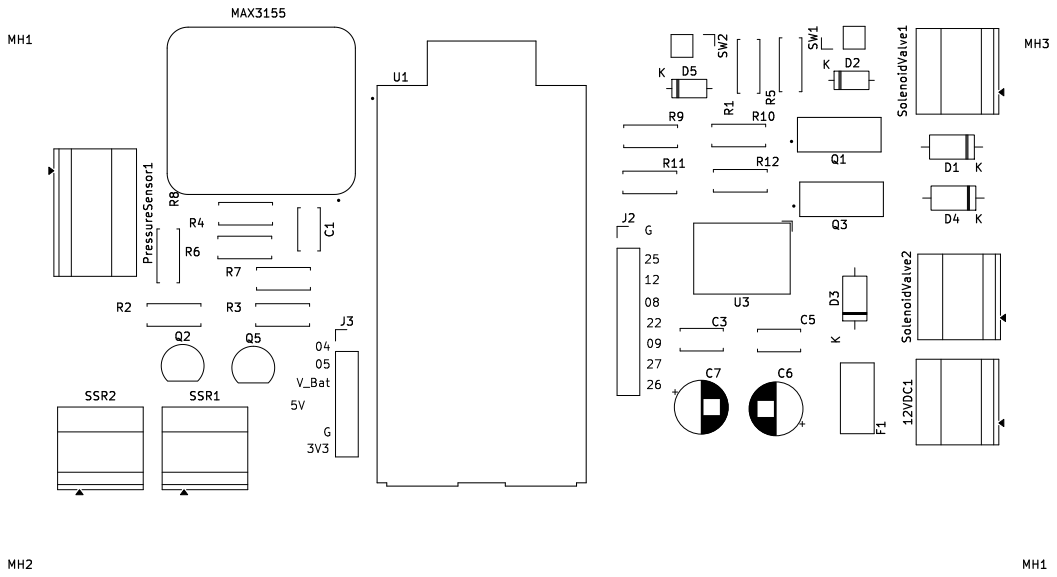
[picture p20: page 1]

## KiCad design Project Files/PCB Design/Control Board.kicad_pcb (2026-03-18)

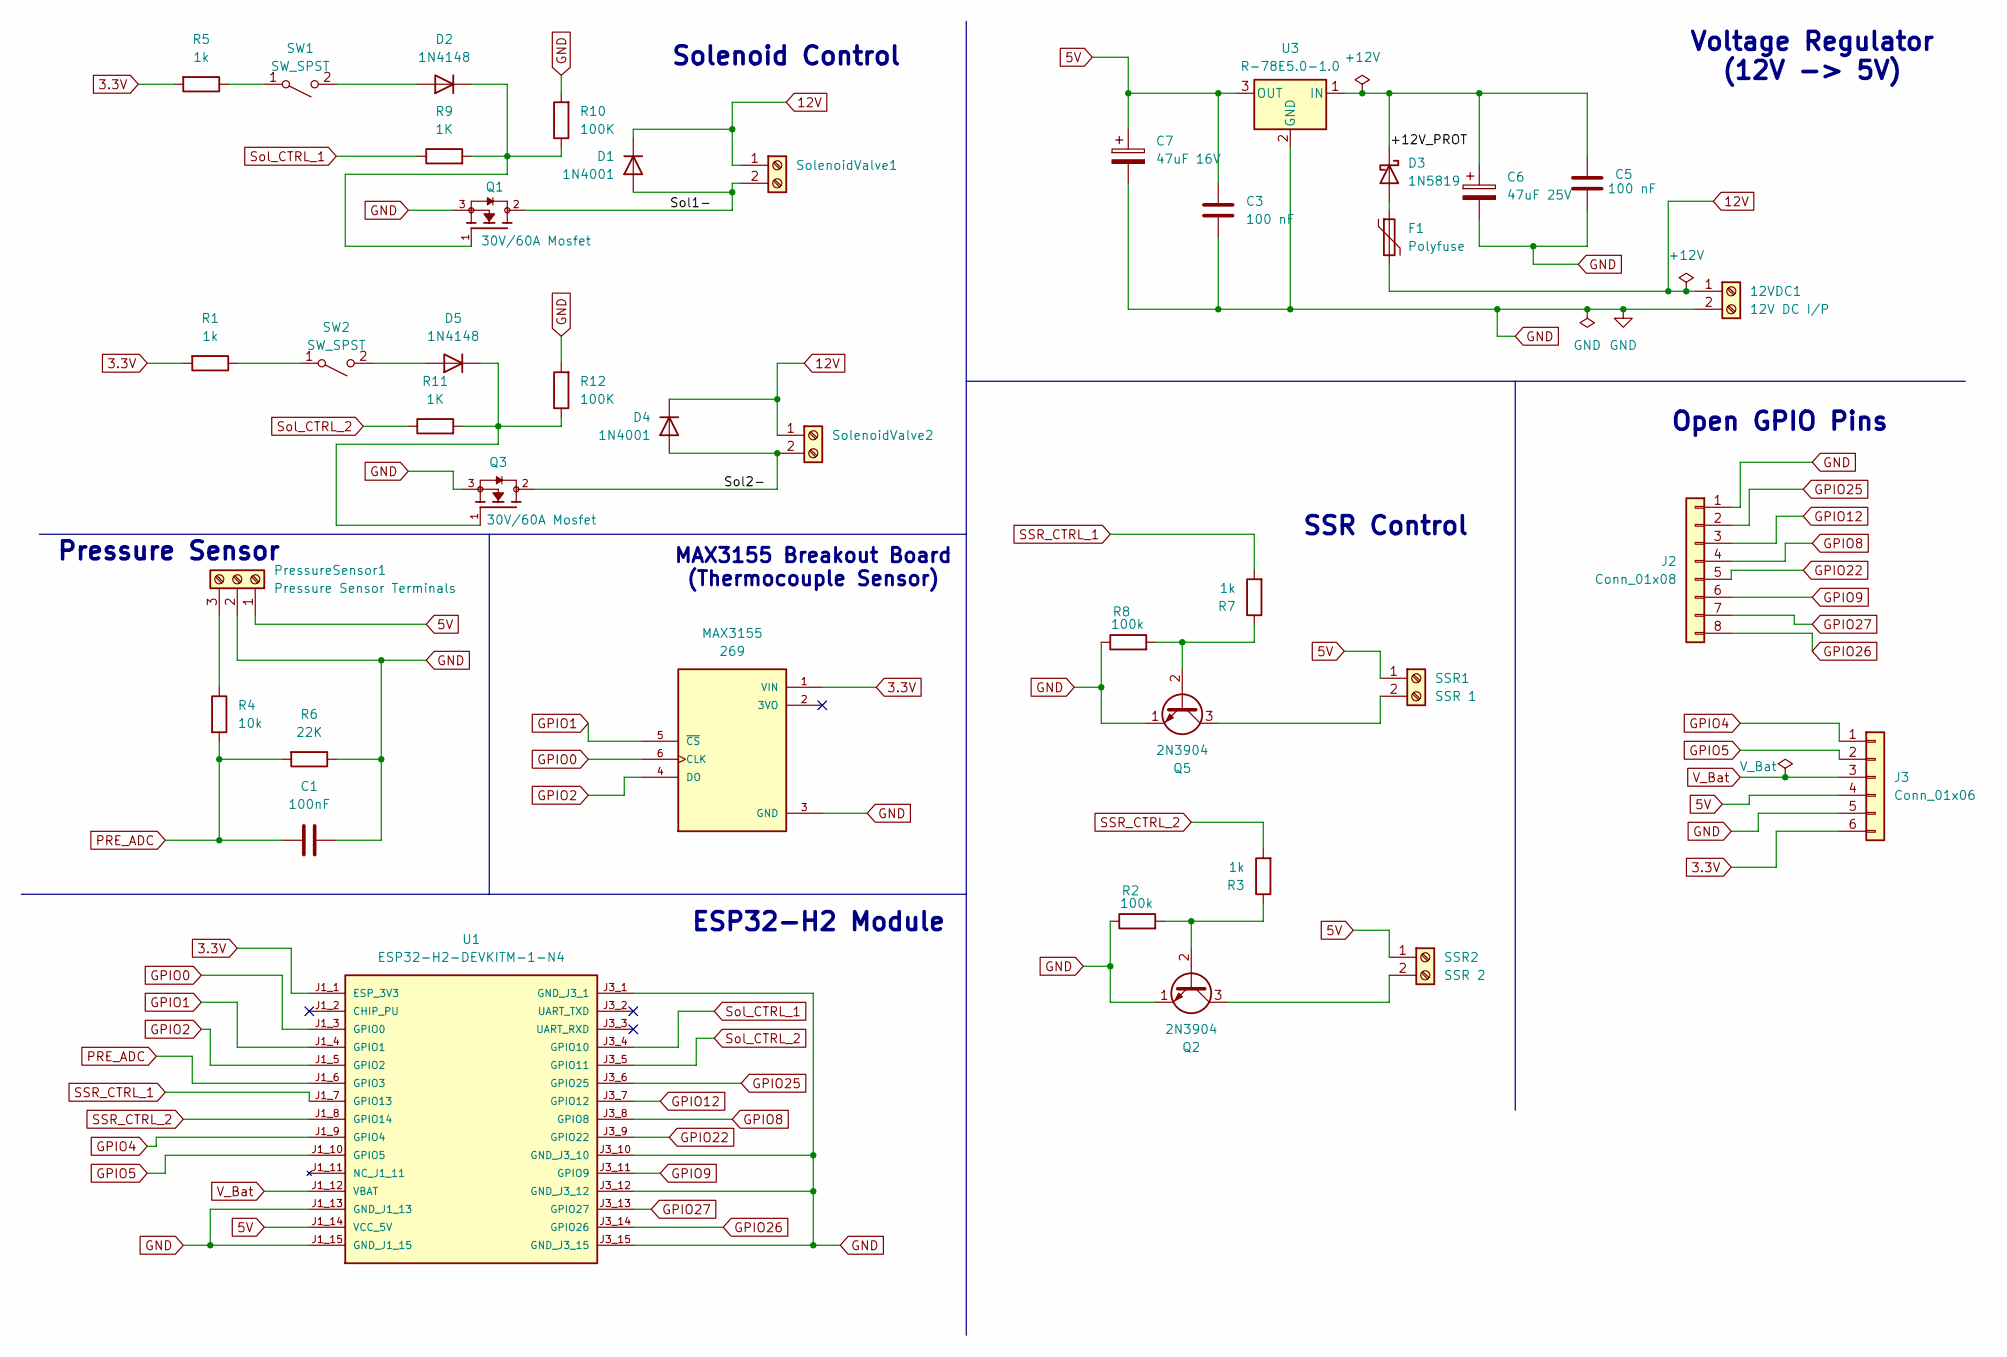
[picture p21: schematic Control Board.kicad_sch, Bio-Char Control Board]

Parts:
12VDC1: 12V DC I/P; TerminalBlock_Phoenix_MKDS-1,5-2-5.08_1x02_P5.08mm_Horizont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
C1: 100nF; C_Disc_D5.0mm_W2.5mm_P5.00mm
C3, C5: 100 nF; C_Disc_D5.0mm_W2.5mm_P5.00mm
C6: 47uF 25V; CP_Radial_D6.3mm_P2.50mm
C7: 47uF 16V; CP_Radial_D6.3mm_P2.50mm
D1, D4: 1N4001; D_DO-41_SOD81_P10.16mm_Horizontal
D2, D5: 1N4148; D_DO-35_SOD27_P7.62mm_Horizontal
D3: 1N5819; D_DO-41_SOD81_P10.16mm_Horizontal
F1: Polyfuse; Fuse_BelFuse_0ZRE0008FF_L8.3mm_W3.8mm
J2: Conn_01x08; PinHeader_1x08_P2.54mm_Vertical
J3: Conn_01x06; PinHeader_1x06_P2.54mm_Vertical
MAX3155: 269; MODULE_269; PARTREV 2.0
PressureSensor1: Pressure Sensor Terminals; TerminalBlock_Phoenix_MKDS-1,5-3-5.08_1x03_P5.08mm_Horizont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
Q1, Q3: 30V/60A Mosfet; TO254P1067X483X2057-3; PARTREV 4/22/09
Q2, Q5: 2N3904; TO-92_Inline
R1, R3, R5, R7: 1k; R_Axial_DIN0207_L6.3mm_D2.5mm_P7.62mm_Horizontal
R2, R8: 100k; R_Axial_DIN0207_L6.3mm_D2.5mm_P7.62mm_Horizontal
R4: 10k; R_Axial_DIN0207_L6.3mm_D2.5mm_P7.62mm_Horizontal
R6: 22K; R_Axial_DIN0207_L6.3mm_D2.5mm_P7.62mm_Horizontal
R9, R11: 1K; R_Axial_DIN0207_L6.3mm_D2.5mm_P7.62mm_Horizontal
R10, R12: 100K; R_Axial_DIN0207_L6.3mm_D2.5mm_P7.62mm_Horizontal
SSR1: SSR 1; TerminalBlock_Phoenix_MKDS-1,5-2-5.08_1x02_P5.08mm_Horizont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
SSR2: SSR 2; TerminalBlock_Phoenix_MKDS-1,5-2-5.08_1x02_P5.08mm_Horizont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
SW1, SW2: SW_SPST; PinHeader_1x02_P2.54mm_Vertical
SolenoidValve1, SolenoidValve2: TerminalBlock_Phoenix_MKDS-1,5-2-5.08_1x02_P5.08mm_Horizont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
U1: ESP32-H2-DEVKITM-1-N4; MODULE_ESP32-H2-DEVKITM-1-N4; PARTREV 1.2
U3: R-78E5.0-1.0; Converter_DCDC_RECOM_R-78E-0.5_THT

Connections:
3.3V: J3.6, MAX3155.1 (VIN), R1.2, R5.2, U1.J1_1 (ESP_3V3)
5V: C3.1, C7.1, J3.4, PressureSensor1.1, SSR1.1, SSR2.1, U1.J1_14 (VCC_5V), U3.3 (OUT)
12V: 12VDC1.1, D1.1 (K), D4.1 (K), F1.2, SolenoidValve1.1, SolenoidValve2.1
/+12V_PROT: C5.1, C6.1, D3.1 (K), U3.1 (IN)
/Sol1-: D1.2 (A), Q1.2, SolenoidValve1.2
/Sol2-: D4.2 (A), Q3.2, SolenoidValve2.2
GND: 12VDC1.2, C1.1, C3.2, C5.2, C6.2, C7.2, J2.1, J3.5, MAX3155.3 (GND), PressureSensor1.2, Q1.3, Q2.1 (E), Q3.3, Q5.1 (E), R2.1, R6.1, R8.1, R10.2, R12.2, U1.J1_13 (GND_J1_13), U1.J1_15 (GND_J1_15), U1.J3_1 (GND_J3_1), U1.J3_10 (GND_J3_10), U1.J3_12 (GND_J3_12), U1.J3_15 (GND_J3_15), U3.2 (GND)
GPIO0: MAX3155.6 (CLK), U1.J1_3 (GPIO0)
GPIO1: MAX3155.5 (~CS), U1.J1_4 (GPIO1)
GPIO2: MAX3155.4 (DO), U1.J1_5 (GPIO2)
GPIO4: J3.1, U1.J1_9 (GPIO4)
GPIO5: J3.2, U1.J1_10 (GPIO5)
GPIO8: J2.4, U1.J3_8 (GPIO8)
GPIO9: J2.6, U1.J3_11 (GPIO9)
GPIO12: J2.3, U1.J3_7 (GPIO12)
GPIO22: J2.5, U1.J3_9 (GPIO22)
GPIO25: J2.2, U1.J3_6 (GPIO25)
GPIO26: J2.8, U1.J3_14 (GPIO26)
GPIO27: J2.7, U1.J3_13 (GPIO27)
unnamed: D2.2 (A), SW1.2 (B)
unnamed: D2.1 (K), Q1.1, R9.2, R10.1
unnamed: D3.2 (A), F1.1
unnamed: D5.2 (A), SW2.2 (B)
unnamed: D5.1 (K), Q3.1, R11.2, R12.1
unnamed: PressureSensor1.3, R4.1
unnamed: Q2.2 (B), R2.2, R3.1
unnamed: Q2.3 (C), SSR2.2
unnamed: Q5.2 (B), R7.1, R8.2
unnamed: Q5.3 (C), SSR1.2
unnamed: R5.1, SW1.1 (A)
unnamed: R1.1, SW2.1 (A)
PRE_ADC: C1.2, R4.2, R6.2, U1.J1_6 (GPIO3)
SSR_CTRL_1: R7.2, U1.J1_7 (GPIO13)
SSR_CTRL_2: R3.2, U1.J1_8 (GPIO14)
Sol_CTRL_1: R9.1, U1.J3_4 (GPIO10)
Sol_CTRL_2: R11.1, U1.J3_5 (GPIO11)
V_Bat: J3.3, U1.J1_12 (VBAT)

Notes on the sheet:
SSR Control
Pressure Sensor
Voltage Regulator (12V -> 5V)
MAX3155 Breakout Board (Thermocouple Sensor)
Solenoid Control
ESP32-H2 Module
Open GPIO Pins

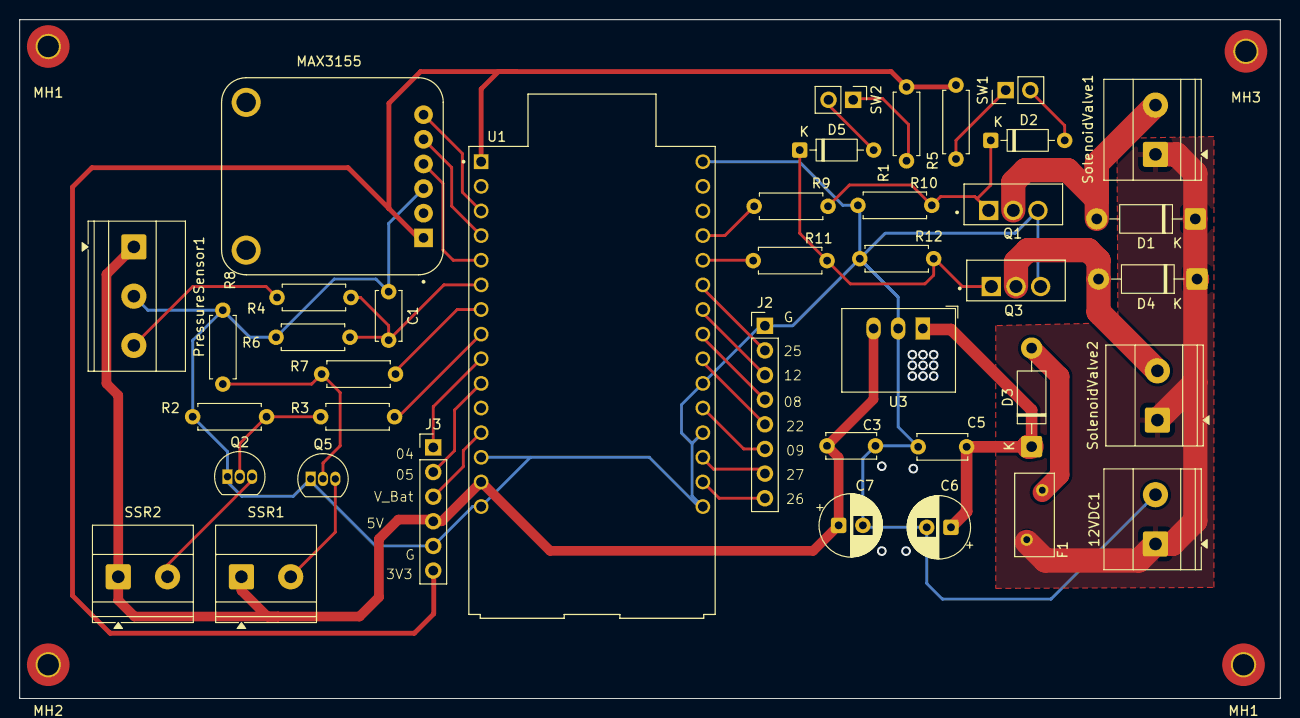
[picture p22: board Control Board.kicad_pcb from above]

Board: 2 copper layers, 130.0 x 70.0 mm, 44 parts (0 on the bottom side), 37 nets.

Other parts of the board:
MH1, MH1#2, MH2, MH3: MountingHole_2.2mm_M2_Pad_TopBottom

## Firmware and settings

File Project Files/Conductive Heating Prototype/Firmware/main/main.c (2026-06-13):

/**
 * @file main.c
 * @brief Bio-Char Control Board v0.1.0 — Integrated Control System
 *        ESP-IDF port of the Arduino Dryness_test_PCB firmware
 *
 * Target:  ESP32-H2-DEVKITM-1-N4
 * SDK:     ESP-IDF v5.x
 *
 * Pin Configuration (corrected from PCB schematic — see notes below):
 *   GPIO0  → MAX31855 CLK
 *   GPIO1  → MAX31855 CS
 *   GPIO2  → MAX31855 DO (MISO — read-only, no MOSI needed)
 *   GPIO3  → Pressure Sensor ADC  (ADC1_CH2, 0–100 PSI via voltage divider)
 *   GPIO4  → SSR 1 / Heater       (active HIGH — drives BJT base to complete SSR circuit)
 *   GPIO5  → SSR 2                (reserved, not currently active — see commented code)
 *   GPIO10 → Solenoid Valve 1     (MOSFET-driven)
 *   GPIO11 → Solenoid Valve 2     (reserved, not currently active — see commented code)
 *
 * PIN CONFIGURATION NOTES:
 *   The original PCB schematic (v0.3.0) assigned GPIO0–GPIO7 differently based on the
 *   KiCad footprint. After bring-up, GPIO8 and GPIO9 were found to be internally tied
 *   to the ESP32-H2's 32 MHz crystal oscillator and cannot be used as general-purpose I/O.
 *   GPIO14 and GPIO15 are similarly reserved for the 32 kHz RTC crystal on some variants.
 *   The SPI and ADC assignments above reflect the remapped working configuration.
 *
 * HEATER/SSR CHANGE vs ARDUINO VERSION:
 *   The Arduino version used active LOW (GPIO4 LOW = SSR ON, sinking to GND).
 *   This board uses a BJT (NPN) between the ESP32 GPIO and the SSR input:
 *     GPIO4 HIGH → BJT base HIGH → collector pulls SSR input LOW → SSR ON
 *     GPIO4 LOW  → BJT OFF → SSR input floating/HIGH → SSR OFF
 *   set_heater() has been updated accordingly.
 *
 * KNOWN ERRORS / ISSUES:
 *   1. ADC non-linearity at low raw values (<350): readings below ~0.5 PSI may
 *      fluctuate. The DRY_PRESSURE_MAX threshold (1.0 PSI) provides enough
 *      headroom for reliable detection.
 *   2. MAX31855 returns NAN on first read after power-on (~100ms settling time).
 *      The EMA initialisation handles this gracefully — temp_ema stays NAN until
 *      a valid reading arrives.
 *   3. GPIO3 on ESP32-H2 is shared with the JTAG interface (MTDI). Disconnect
 *      the JTAG debugger before running in production, or remap to GPIO4/5 if
 *      debugging under load is required.
 */

#include <stdio.h>
#include <math.h>
#include <string.h>
#include "freertos/FreeRTOS.h"
#include "freertos/task.h"
#include "driver/gpio.h"
#include "driver/spi_master.h"
#include "esp_adc/adc_oneshot.h"
#include "esp_log.h"
#include "esp_timer.h"

static const char *TAG = "biochar";

// ===============================================================
// -------------------- MAX31855 THERMOCOUPLE --------------------
// ===============================================================
#define PIN_MAXCLK   GPIO_NUM_0    // MAX31855 Clock (SPI CLK)
#define PIN_MAXCS    GPIO_NUM_1    // MAX31855 Chip Select
#define PIN_MAXDO    GPIO_NUM_2    // MAX31855 Data Out (MISO — read-only)

// ===============================================================
// -------------------------- PINS --------------------------------
// ===============================================================
#define PIN_ADC_PRESSURE  ADC_CHANNEL_2   // GPIO3 — Pressure sensor (ADC1_CH2)
#define PIN_VALVE         GPIO_NUM_10     // GPIO10 — Solenoid Valve 1 (MOSFET)
#define PIN_HEATER        GPIO_NUM_4      // GPIO4 — SSR 1 (active HIGH → BJT → SSR)

// Reserved for future use — uncomment when second SSR and valve are needed
// #define PIN_SSR2    GPIO_NUM_5    // GPIO5  — SSR 2 circuit (not currently active)
// #define PIN_VALVE2  GPIO_NUM_11   // GPIO11 — Solenoid Valve 2 (not currently active)

// ===============================================================
// ------------------- PRESSURE CALIBRATION ----------------------
// ===============================================================
#define ADC_ZERO      320.0f    // ADC raw value at 0 PSI
#define ADC_FULL      3008.0f   // ADC raw value at 100 PSI

// ===============================================================
// --------------------- VALVE HYSTERESIS ------------------------
// ===============================================================
#define PSI_ON_THRESHOLD   8.0f   // Open valve above this pressure
#define PSI_OFF_THRESHOLD  7.0f   // Close valve below this pressure

// ===============================================================
// ------------------- DRY DETECTION (PRESSURE) ------------------
// ===============================================================
#define CYCLE_START_PSI   2.0f       // Pressure must exceed this to start a cycle
#define DRY_PRESSURE_MAX  1.0f       // PSI below which dry detection is considered
#define DRY_TIME_MS       15000UL    // Must stay dry for this long to latch

// ===============================================================
// ------------------ HEATER TEMPERATURE CONTROL -----------------
// ===============================================================
#define SETPOINT_C   200.0f    // Target temperature (°C)
#define HYST_C       2.0f      // Hysteresis band (°C)
#define KP           0.03f     // Proportional gain
#define EMA_ALPHA    0.10f     // Exponential moving average weight
#define WINDOW_MS    2000      // PWM window period (ms)

// ===============================================================
// --------------------------- STATE -----------------------------
// ===============================================================
static bool    valve_on            = false;
static bool    cycle_active        = false;
static bool    dry_latched         = false;
static int64_t dry_candidate_start = 0;
static float   temp_ema            = NAN;
static int64_t window_start        = 0;

static spi_device_handle_t       max31855_handle;
static adc_oneshot_unit_handle_t adc_handle;

// ===============================================================
// -------------------------- HELPERS ----------------------------
// ===============================================================
static float fmap(float x, float in_min, float in_max, float out_min, float out_max) {
    return (x - in_min) * (out_max - out_min) / (in_max - in_min) + out_min;
}

static float adc_to_psi(int adc_raw) {
    return fmap((float)adc_raw, ADC_ZERO, ADC_FULL, 0.0f, 100.0f);
}

static void set_heater(bool on) {
    // Active HIGH: GPIO4 HIGH → BJT base HIGH → collector completes SSR circuit → SSR ON
    // Active LOW (off):  GPIO4 LOW  → BJT OFF → SSR OFF
    gpio_set_level(PIN_HEATER, on ? 1 : 0);
}

// ===============================================================
// -------------------- MAX31855 SPI READ ------------------------
// ===============================================================
/**
 * Reads a 32-bit frame from the MAX31855 over SPI.
 *
 * Frame layout:
 *   Bits [31:18] — Thermocouple temp, 14-bit signed, 0.25°C/LSB
 *   Bit  [16]   — Fault bit (1 = fault present)
 *   Bits [15:4] — Internal junction temp (not used here)
 *   Bits [3:0]  — Fault flags (OC, SCG, SCV)
 */
static esp_err_t max31855_read(float *temp_c, bool *fault) {
    uint8_t rx_buf[4] = {0};

    spi_transaction_t t = {
        .length    = 32,
        .rx_buffer = rx_buf,
    };

    esp_err_t ret = spi_device_polling_transmit(max31855_handle, &t);
    if (ret != ESP_OK) return ret;

    uint32_t raw = ((uint32_t)rx_buf[0] << 24) |
                   ((uint32_t)rx_buf[1] << 16) |
                   ((uint32_t)rx_buf[2] <<  8) |
                   ((uint32_t)rx_buf[3]);

    *fault = (raw & (1UL << 16)) != 0;

    // Sign-extend the 14-bit thermocouple value
    int16_t tc_raw = (int16_t)((raw >> 18) & 0x3FFF);
    if (tc_raw & 0x2000) tc_raw |= 0xC000;
    *temp_c = tc_raw * 0.25f;

    return ESP_OK;
}

// ===============================================================
// ----------------------- INITIALISATION ------------------------
// ===============================================================
static void init_spi(void) {
    spi_bus_config_t bus_cfg = {
        .miso_io_num   = PIN_MAXDO,
        .mosi_io_num   = -1,           // MAX31855 is read-only, no MOSI
        .sclk_io_num   = PIN_MAXCLK,
        .quadwp_io_num = -1,
        .quadhd_io_num = -1,
        .max_transfer_sz = 4,
    };
    ESP_ERROR_CHECK(spi_bus_initialize(SPI2_HOST, &bus_cfg, SPI_DMA_CH_AUTO));

    spi_device_interface_config_t dev_cfg = {
        .clock_speed_hz = 1 * 1000 * 1000,  // 1 MHz (MAX31855 max: 5 MHz)
        .mode           = 0,                  // CPOL=0, CPHA=0
        .spics_io_num   = PIN_MAXCS,
        .queue_size     = 1,
    };
    ESP_ERROR_CHECK(spi_bus_add_device(SPI2_HOST, &dev_cfg, &max31855_handle));
}

static void init_adc(void) {
    adc_oneshot_unit_init_cfg_t unit_cfg = {
        .unit_id = ADC_UNIT_1,
    };
    ESP_ERROR_CHECK(adc_oneshot_new_unit(&unit_cfg, &adc_handle));

    adc_oneshot_chan_cfg_t chan_cfg = {
        .bitwidth = ADC_BITWIDTH_12,
        .atten    = ADC_ATTEN_DB_12,   // Full 0–3.3 V range
    };
    ESP_ERROR_CHECK(adc_oneshot_config_channel(adc_handle, PIN_ADC_PRESSURE, &chan_cfg));
}

static void init_gpio(void) {
    gpio_config_t io_conf = {
        .pin_bit_mask  = (1ULL << PIN_VALVE) | (1ULL << PIN_HEATER),
        .mode          = GPIO_MODE_OUTPUT,
        .pull_up_en    = GPIO_PULLUP_DISABLE,
        .pull_down_en  = GPIO_PULLDOWN_ENABLE,   // Pull-down keeps BJT off at boot
        .intr_type     = GPIO_INTR_DISABLE,
    };
    ESP_ERROR_CHECK(gpio_config(&io_conf));

    gpio_set_level(PIN_VALVE,   0);   // Valve 1 OFF
    gpio_set_level(PIN_HEATER,  0);   // SSR 1 OFF (BJT base LOW)

    // Uncomment when SSR 2 and Valve 2 circuits are populated on the board:
    // gpio_config_t io_conf2 = {
    //     .pin_bit_mask  = (1ULL << PIN_SSR2) | (1ULL << PIN_VALVE2),
    //     .mode          = GPIO_MODE_OUTPUT,
    //     .pull_up_en    = GPIO_PULLUP_DISABLE,
    //     .pull_down_en  = GPIO_PULLDOWN_ENABLE,
    //     .intr_type     = GPIO_INTR_DISABLE,
    // };
    // ESP_ERROR_CHECK(gpio_config(&io_conf2));
    // gpio_set_level(PIN_SSR2,   0);
    // gpio_set_level(PIN_VALVE2, 0);
}

// ===============================================================
// ------------------------- MAIN TASK ---------------------------
// ===============================================================
static void control_task(void *arg) {
    ESP_LOGI(TAG, "╔════════════════════════════════════════════════╗");
    ESP_LOGI(TAG, "║   SYSTEM READY: INTEGRATED CONTROL SYSTEM     ║");
    ESP_LOGI(TAG, "║   - Pressure Control + Valve 1                 ║");
    ESP_LOGI(TAG, "║   - Temperature Control + SSR 1 (Heater)       ║");
    ESP_LOGI(TAG, "║   - Dry Boiler Protection                      ║");
    ESP_LOGI(TAG, "╚════════════════════════════════════════════════╝");
    ESP_LOGI(TAG, "Pin map:");
    ESP_LOGI(TAG, "  GPIO0  → MAX31855 CLK");
    ESP_LOGI(TAG, "  GPIO1  → MAX31855 CS");
    ESP_LOGI(TAG, "  GPIO2  → MAX31855 DO");
    ESP_LOGI(TAG, "  GPIO3  → Pressure Sensor ADC");
    ESP_LOGI(TAG, "  GPIO4  → SSR 1 (active HIGH, BJT driver)");
    ESP_LOGI(TAG, "  GPIO5  → SSR 2 (reserved)");
    ESP_LOGI(TAG, "  GPIO10 → Solenoid Valve 1");
    ESP_LOGI(TAG, "  GPIO11 → Solenoid Valve 2 (reserved)");

    window_start = esp_timer_get_time() / 1000LL;

    while (1) {
        int64_t now = esp_timer_get_time() / 1000LL;   // ms

        // ------------------- TEMPERATURE -------------------
        float temp_c = NAN;
        bool  fault  = false;
        esp_err_t tc_err   = max31855_read(&temp_c, &fault);
        bool  temp_valid   = (tc_err == ESP_OK) && !fault && !isnan(temp_c);

        if (temp_valid) {
            if (isnan(temp_ema)) temp_ema = temp_c;
            else temp_ema = EMA_ALPHA * temp_c + (1.0f - EMA_ALPHA) * temp_ema;
        }

        // -------------------- PRESSURE ---------------------
        int   adc_raw = 0;
        adc_oneshot_read(adc_handle, PIN_ADC_PRESSURE, &adc_raw);
        float psi = adc_to_psi(adc_raw);

        // ------------------- VALVE CONTROL -----------------
        if (!valve_on && psi >= PSI_ON_THRESHOLD)        valve_on = true;
        else if (valve_on && psi <= PSI_OFF_THRESHOLD)   valve_on = false;
        gpio_set_level(PIN_VALVE, valve_on ? 1 : 0);

        // ------------------- DRY DETECTION -----------------
        if (!dry_latched) {
            if (!cycle_active && psi >= CYCLE_START_PSI)
                cycle_active = true;

            if (cycle_active) {
                if (psi <= DRY_PRESSURE_MAX) {
                    if (dry_candidate_start == 0)
                        dry_candidate_start = now;
                    if ((now - dry_candidate_start) >= (int64_t)DRY_TIME_MS)
                        dry_latched = true;
                } else {
                    dry_candidate_start = 0;
                }
            }
        }

        // ------------------- HEATER CONTROL ----------------
        bool  heater_on = false;
        float duty      = 0.0f;

        if (!dry_latched && temp_valid) {
            float error = SETPOINT_C - temp_ema;
            duty = (temp_ema >= SETPOINT_C + HYST_C) ? 0.0f : KP * error;
            if (duty < 0.0f) duty = 0.0f;
            if (duty > 1.0f) duty = 1.0f;

            if ((now - window_start) >= (int64_t)WINDOW_MS)
                window_start = now;

            heater_on = ((now - window_start) < (int64_t)(duty * WINDOW_MS));
        }

        set_heater(heater_on);

        // ------------------- LOG OUTPUT --------------------
        ESP_LOGI(TAG,
            "P=%.2fpsi | Valve=%s | Heater=%s | BJT=%s | DRY=%s | T=%s | Duty=%.0f%%",
            psi,
            valve_on    ? "ON"   : "OFF",
            heater_on   ? "ON"   : "OFF",
            gpio_get_level(PIN_HEATER) ? "HIGH" : "LOW",
            dry_latched ? "YES"  : "NO",
            temp_valid  ? (char[16]){0}  : "NA",
            duty * 100.0f
        );

        if (temp_valid) {
            ESP_LOGI(TAG, "  T_ema=%.1f°C", temp_ema);
        }

        vTaskDelay(pdMS_TO_TICKS(300));
    }
}

// ===============================================================
// --------------------------- ENTRY POINT -----------------------
// ===============================================================
void app_main(void) {
    init_spi();
    init_adc();
    init_gpio();

    xTaskCreate(control_task, "control_task", 4096, NULL, 5, NULL);
}

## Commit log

2025-10-10 Document Flash System Prototype test cases
    Added initial test cases for Flash System Prototype, including solenoid control and temperature sensing.
2026-02-13 Update project status: SSR control integration, and initial charring test results
    - Resealed chamber valves to resolve pressure leaks
    - Recalibrated pressure sensor against manual gauge
    - Integrated SSR-based hotplate control
    - Validated dryness detection logic under low-pressure conditions
    - Conducted initial bread charring experiment (~110C, 2h40m)
    - Observed soot deposition inside chamber
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2026-02-19 Control Board Schematics
    - Updated the Schematics for better understanding
    [Control Board.kicad_sch]
2026-03-18 Update Control Board.md
    Update Control Board documentation with BOM and specifications
    - Added complete BOM summary and component table
    - Added power distribution diagram
    - Added pin assignments and GPIO mapping
    - Added assembly instructions and testing procedure
    - Added safety considerations
    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
2026-03-18 Add files via upload
    Update schematic to v0.3.0
    - Updated component values
    - Verified all connections
    - Ready for PCB layout
    [Control Board.kicad_sch]
2026-03-18 Add files via upload
    Add verified Mouser BOM with complete pricing
    - 18 component types, 40 total items
    - Total cost: $48.12 (verified March 2026)
    - All Mouser part numbers verified
    - Automatic pricing formulas included
    - Ready to order directly from Mouser
    [Bio_Char_BOM_Mouser_FINAL.xlsx]
2026-03-18 Add files via upload
    Add KiCad PCB layout and project files
    - Complete PCB layout with routing
    - All components placed and connected
    - Design rules verified
    - Ready for manufacturing
    [Control Board.kicad_pcb]
2026-03-18 Add files via upload
    Add manufacturing Gerber files
    - Complete gerber set for PCB fabrication
    - Top and bottom copper layers
    - Soldermask and silkscreen layers
    - Edge cuts and board outline
    - Ready to send to manufacturer
2026-03-18 Add files via upload
    Add drill files for PCB manufacturing
    - NC drill files for through-holes and vias
    - Compatible with standard CNC drilling equipment
    [Control Board.drl]
2026-03-20 Update BOM with requested items
    - Added Camera Pole Mount Bracket from Amazon
    - Added Fuel Cell Bulkhead Adapter Fittings from Summit Racing
    - Added three PTFE-related components from McMaster-Carr
    - Added MEAN WELL RSP-2400 power supply
    [1st_Action_Pyrolysis_BOM.ods]
2026-03-20 Add 8 more new items to the BOM file
    [1st_Action_Pyrolysis_BOM.ods]
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2026-03-20 Fix column headers and alignment in BOM
    [1st_Action_Pyrolysis_BOM.ods]
2026-03-20 Auto commit
    [1inID_304ss_bulkhead fitting.FCStd, 4464K53_NO THREADS_304 Stainless Steel Threaded Pipe Fitting.FCStd, Custom tangent bulkhead fitting.FCStd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]
2026-03-20 Update progress report with recent project developments
    Added detailed progress updates on project BOM and testing results.
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2026-03-20 Update progress report with new material specifications
    Added details about materials and components for the induction coil system.
2026-03-20 Add ball bearings and remove duplicates
    [1st_Action_Pyrolysis_BOM.ods]
2026-03-23 docs(BOM): Add an 'Acquired' checklist column
    - Added a new `Acquired` column to the Markdown table in `Project Files/BOM/1st_Action_Pyrolysis_BOM.md` to track item procurement.
    - Initialized all rows with a `[ ]` check mark box.
2026-03-31 Mark items as acquired in BOM
    Updated the status of several items to 'acquired' and marked them accordingly.
2026-04-25 Document induction heating experiment results
    Added detailed observations and results from recent induction heating experiments, including temperature measurements and material efficiency comparisons.
2026-05-19 Add Biochar Toilet presentation slide deck
    Created a new Presentations directory and added an HTML slide deck
    outlining the Biochar Toilet project, its mission, and the technical
    architecture (including the induction innovations and magnetite matrix).
2026-05-19 docs: move progress report to correct file and update readme project state
    Moves the "Flash System Prototype - Test 1" section from `README.md`
    into `Project Files/Progress Reports.md`, preserving reverse chronological
    ordering.
    Replaces the old section in `README.md` with an updated "Project State" section
    detailing the completion of Phase 1 and preparations for Phase 2, with
    a link to the progress reports.
2026-05-20 Document valorization system in DESIGN_IDEAS.md
    Added a section to `DESIGN_IDEAS.md` documenting the usage of a
    modified pressure cooker with a 1" solenoid, large induction heating
    loop, and the role of the pressure sensor in monitoring valorization.
2026-05-20 Add "Why Pyrolysis Over Composting" slide to presentation
    - Updates Biochar_Toilet_Slide_Deck.html to include a new slide addressing the critique of pyrolysis complexity compared to composting toilets.
    - The new slide highlights The Pathogen Failsafe, Supply Chain Independence, Contaminant Destruction, and Biochar vs. Humus Output.
    - Updates CSS for `.tiled-content` and `.tile` to properly format the 2x2 grid layout.
    - Increments slide numbers in HTML comments to keep the correct slide order.
2026-05-20 Add "Why Not Sewage" and "Why Pyrolysis Over Incineration" slides
    - Extracted two additional slides from the provided mockup and integrated them into `Presentations/Biochar_Toilet_Slide_Deck.html`.
    - Inserted "Beyond the Flush: Why Not Sewage?" immediately after the traditional sewage deep dive.
    - Inserted "Why Pyrolysis Over Incineration?" immediately after the incinerating toilets deep dive.
    - Renumbered slide comments to maintain the correct sequential order (now up to 16 slides).
2026-05-20 feat: integrate new slides and CSS into presentation deck
    Added three new presentation slides to `Biochar_Toilet_Slide_Deck.html`:
    1. Visualizing the Divergence Curve (Slide 13)
    2. Off-Grid Power & Energy Buffering (Slide 16)
    3. Local Fabrication & The Toolchain (Slide 17)
    Also extracted and appended the necessary CSS styles for the SVG chart visualization to the document's `<style>` section. All subsequent slides and their numbering comments have been updated to refle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
2026-05-21 feat: implement interactive presentation mode with fullscreen support
    Added a "Present" button to the bottom right of `Biochar_Toilet_Slide_Deck.html` that toggles a fullscreen presentation mode.
    Implemented JavaScript logic to hook into the Fullscreen API, dynamically scale active `.slide-container` elements to fit the viewport, hide inactive slides, and handle navigation via `ArrowRight` an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
2026-05-22 Update presentation: remove border radius from slide 1 logo
    This commit removes the `border-radius: 50%` style from the logo image
    on slide 1 to prevent its corners from being cut off.
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2026-05-25 Update Progress Reports with PCB Control Board details
    Added detailed progress report for PCB Control Board v0.1.0, including hardware rework, initial testing results, and design completion.
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2026-05-25 docs: consolidate comparison slides and add concrete stats
    - Consolidated slides 6-9 into a single "Why Pyrolysis Over Alternatives?" slide focusing on safety, convenience, energy efficiency, and rapid heating.
    - Updated "The Infrastructure Gap" slide with concrete 2025 WHO/UNICEF statistics.
    - Added tasks to TODO.md to capture the team's story and write a snappy script for the presentation.
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2026-06-10 fix(presentations): fix grid layout override in presentation mode
    The `.presentation-mode .slide-container.active` CSS rule forcefully
    applied `display: flex`, which inadvertently broke slides using CSS Grid,
    such as the "Phase 1 Control Board" and "Internal Coil Design" slides
    using the `.bleed-image-layout` class.
    Added a specific override for `.bleed-image-layout` when active in
    presentation mode, and cleaned up problematic inline dimensions to
    ensure they render correctly.
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2026-06-11 fix: add esp_driver_gpio and esp_driver_spi to CMakeLists.txt
    In ESP-IDF v6, the monolithic `driver` component is deprecated in favor of specific driver components.
    This updates the firmware CMake configuration to explicitly declare dependencies on
    `esp_driver_gpio` and `esp_driver_spi` via `PRIV_REQUIRES` in `main/CMakeLists.txt`.
2026-06-11 Update induction hardware slides in presentation deck
    - Replaced obsolete 'Potted Internal Coil' slide with updated 'Induction Hardware: Current Development Status'.
    - Added new 'From Kitchenware to Prototype' slide detailing the fabrication process and accessibility principles.
    - Updated FontAwesome icon to a free variant (`fa-kitchen-set`) for correct rendering.
    - Removed extraneous markdown backticks from the source content.
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2026-06-13 Fix CMake build by using driver component instead of standalone gpio/spi drivers
    This updates the `CMakeLists.txt` for the ESP32-H2 firmware so that it uses the umbrella `driver` component rather than `esp_driver_gpio` and `esp_driver_spi`. In ESP-IDF v5.2, these specific drivers are not available as standalone components and are bundled under `driver`. This addresses the CMake resolution failures.
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2026-06-16 🎨 Palette: Fix keyboard navigation focus bug in presentation mode
2026-06-16 ⚡ Bolt: Throttle window resize event in presentation deck
    - Wrapped `scaleActiveSlide` in a `requestAnimationFrame` throttle within the resize event listener in `Biochar_Toilet_Slide_Deck.html`.
    - Prevents layout thrashing and main-thread blocking during continuous window resize events.
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2026-06-18 feat(ux): add presentation progress bar and explicit keyboard hints
    Added a visual progress bar with ARIA roles to the top of the custom presentation view to replace lost native browser progress cues. Updated the Present button's `aria-label` and `title` to explicitly mention the keyboard shortcuts (Space/Arrows) needed to navigate, improving screen reader accessibility and general UX discoverability. Updated the `.Jules/palette.md` journal with these critical learnings.
2026-07-02 feat: Expand vapor processing stack blueprint with Syngas Memo concepts
    - Integrates In-Situ Sulfur Fixation (Lime/Magnetite) into Phase 2 of the Mermaid diagram and text.
    - Adds Phase 4 outlining the Sulfur Mitigation "Iron Sponge" dry scrubber.
    - Adds Phase 5 detailing Lean Combustion and the Modular Ceramic Heat Exchanger with a "leaky" slip-fit baffle design.
    - Updates the Mermaid diagram to visualize all phases logically as requested.
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2026-10-23 Add bentonite clay/kitty litter susceptor matrix details to paper
    Explicitly document bentonite clay / kitty litter mixed with magnetite as the initial stage susceptor coupling directly into fecal and urine mass.
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
